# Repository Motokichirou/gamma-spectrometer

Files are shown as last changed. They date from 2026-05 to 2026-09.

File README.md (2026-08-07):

<h1 align="center">Гамма-спектрометр на NaI(Tl)</h1>

<p align="center">
  
  
  
  
  
  
  
</p>

<!-- README-I18N:START -->
<p align="center"><b>Русский</b> | <a href="./README.en.md">English</a></p>
<!-- README-I18N:END -->

Портативный цилиндрический гамма-спектрометр на кристалле NaI(Tl) Ø63×63 мм и ФЭУ Hamamatsu R1307, с интерфейсом USB-C, совместимым с [BecqMoni](https://github.com/Am6er/BecqMoni) / AtomSpectra (протокол shproto).

> 📚 **Документация:** [обзор аппаратной части](docs/ru/hardware.md) · [прошивка](docs/ru/firmware.md) · [протокол shproto](docs/ru/protocol.md) · [ПО на PC](host/README.md) · [симуляции](docs/ru/simulations.md)

---

## Ключевые характеристики

| Параметр | Значение |
|---|---|
| Детектор | NaI(Tl) Ø63×63 мм |
| ФЭУ | Hamamatsu R1307 (8 каскадов, Ø76 мм) |
| Диапазон энергий | 50 кэВ – 3.5 МэВ |
| Целевое FWHM @ Cs-137 | 6.0–6.5 % |
| Каналов спектра | 8192 |
| Скорость счёта | до ~30 000 имп/с |
| МК | STM32G474 @ 170 МГц (12-бит АЦП, 4 Мвыб/с) |
| ВВ питание | 0 … −1500 В (MAX1847 + 8-ступенчатый умножитель CW) |
| Интерфейс | USB-C → UART 600 кбит/с (FT231X), протокол shproto |
| Питание | USB 5 В, ~370 мА |
| Форм-фактор | Цилиндрический стек, платы Ø45 мм |

---

## Аппаратная архитектура

### Стек плат (снизу → вверх)

```
 ┌─────────────────────────────────────────┐
 │  USB/Power board  Ø45 mm               │  ← кабель USB-C
 │  LP5907 · AMS1117 · TPS60400 · FT231X  │
 ├─────────────────────────────────────────┤
 │  HV board         Ø45 mm               │
 │  MAX1847 · IRLML0040 · CW ×8 · −1500 V │
 ├─────────────────────────────────────────┤
 │  MCU board        Ø45 mm               │
 │  STM32G474 · CR-RC² shaper · ADC · SPI │
 ├─────────────────────────────────────────┤
 │  Divider board    Ø42–45 mm            │  ← ФЭУ Hamamatsu R1307 + NaI(Tl)
 │  R1307 divider · MMBTA42 buffers       │
 │  ADA4817-1 TIA (Zt = 499 Ω)            │
 └─────────────────────────────────────────┘
```

Межплатные соединения:
- **Сигнал**: коаксиал RG-178 + U.FL (делитель → МК, ~470 мВ для Cs-137)
- **Питание ±5 В_A**: JST PH 3-пин (МК → делитель)
- **−HV**: экранированный провод ≥5 кВ вдоль края стека (ВВ → делитель)
- **Все прочие сигналы**: pin-header 2×N с шагом 2.54 мм

### Цепь сигнала

```
NaI(Tl) + R1307            Плата делителя                 Плата МК
─────────────    ─────────────────────────────   ──────────────────────────────────
 Сцинтилляция →   Делитель (цепочка 7.72 МОм)   →  CR  (OPAMP1, τ=1 мкс)
 τ_спада=230 нс   Активные буферы (Dy6/7/8)        RC  (OPAMP2, τ=510 нс)
 I_анода(Cs-137)  ADA4817 TIA, Zt=499 Ω, BW≈92 МГц →  PGA ×4 (OPAMP3)
  = 0.94 мА       V_вых = +469 мВ (Cs-137)         V_ADC = baseline 0.408 В
                                                   ADC1_IN12, 4 Мвыб/с
                                                   гистограмма 8192 кан. → USB
```

**Полярность АЦП:** анод забирает ток ⇒ выход TIA вверх ⇒ импульсы **положительны** относительно baseline 0.408 В → `amplitude = sample − baseline`

### Калибровка энергии (по симуляции, модель OPAMP G474)

| Источник | Энергия | Канал АЦП / 8192 |
|---|---|---|
| Am-241 | 59.5 кэВ | 105 |
| Cs-137 | 662 кэВ | 1159 |
| Co-60 | 1.33 МэВ | 2321 |
| Tl-208 | 2.61 МэВ | 4554 |
| Потолок | 3.5 МэВ | 6133 |

---

## Статус проекта

| Задача | Статус |
|---|---|
| Схема — плата USB/питания | ✅ Готово (ERC 0) |
| Схема — плата ВВ | ✅ Готово (ERC 0) |
| Схема — плата МК | ✅ Готово (ERC 0) |
| Схема — плата делителя | ✅ Готово (ERC 0) |
| LTspice: вход TIA (ADA4817) + делитель | ✅ Валидировано (`sim_divider_complete`: Zt=499 Ω, буферы смещены ~96 мкА, диоды B-E) |
| LTspice sim2: шейпер CR-RC² | ✅ Готово (PF=0.202, ширина импульса ~1.5 мкс) |
| LTspice sim3: бюджет шумов | ✅ Готово (σ=76.9 мкВ rms с TIA, 0.25 кан.; 94.4 с прежним AD8000) |
| BOM с MPN + footprint | ✅ Готово (177 комп.: 74 конд. / 17 MPN, 63 R, все активные) |
| Разводка PCB | 🚧 2 слоя, все 4 платы разведены, паритет со схемой 0. Нормы ВВ-зазоров (3 мм/кВ) заданы в `.kicad_dru`. ⚠ Осталось развести 59 мест, где земля подходит к ВВ-цепям ближе нормы |
| Прошивка STM32 | 🚧 Этапы 1–2 + самотест + энергокалибровка во flash работают на Nucleo (shproto, реальная гистограмма); этап 3 — на боевой плате |
| ПО на PC `gammapult` | 🚧 Связь, диагностика, живой спектр, мастер энергокалибровки (GUI + CLI, единый .exe); калибровка совместима с кнопками BecqMoni |

---

## Структура репозитория

```
gamma-spectrometer/
├── docs/
│   ├── adc_mcu_board.md              # Плата МК v1.6 — полная техническая документация
│   ├── divider_board.md              # Плата делителя + ADA4817 TIA
│   ├── usb_power_board.md            # Плата USB/питания — обзор
│   ├── usb_power_board_schematic.md  # Плата USB/питания — детальная схема
│   ├── hv_board_schematic.md         # Плата ВВ — детальная схема
│   ├── cheatsheet_mistakes.md        # Правила проверки и журнал прошлых ошибок
│   └── refs/                         # Даташиты
├── firmware/                         # Прошивка STM32G474 (этапы 1–2 на Nucleo работают)
├── host/                             # ПО на PC `gammapult` (Win32/ImGui, GUI + CLI)
├── pcb/
│   └── gamma_spectrometer/           # Проект KiCad (все 4 платы)
└── simulation/
    ├── models/                       # SPICE-модели (opamp_g474, ADA4817, AD8000)
    ├── scripts/                      # Python-скрипты анализа
    ├── sim1_ad8000.cir               # Устойчивость и полоса AD8000
    ├── sim2_shaper.cir               # Формирователь импульсов CR-RC²
    └── sim3_noise.cir                # Полный бюджет шумов
```

---

## Бюджет шумов (sim3)

| Вклад | FWHM |
|---|---|
| Статистика ФЭУ R1307 + NaI(Tl) | 6.3 % |
| Пульсации ВВ (типично) | 0.3–0.5 % |
| Нелинейность АЦП (12-бит, ENOB ~10.5) | 0.1 % |
| Шум электроники (σ = 94.4 мкВ rms) | **0.064 %** |
| **Итого** | **~6.32 %** |

Шум электроники **на два порядка ниже** статистики ФЭУ — разрешение ограничено ФЭУ, а не электроникой.

---

## Протокол: shproto / AtomSpectra

Совместим с [BecqMoni](https://github.com/Am6er/BecqMoni) и [nanopro](https://github.com/Am6er/nanopro).

- UART 600 000 бит/с, 8N1
- Кадр: `0xFE | CMD | PAYLOAD (с байт-стаффингом) | CRC16-MODBUS | 0xA5`
- Cmd `0x01`: спектр (до 8192 × 32-битных каналов)
- Cmd `0x04`: статус (прошедшее время, CPS, число невалидных импульсов)
- Keep-alive: `0xFF` от ПК каждую ~1 с

---

## Лицензия

Файлы аппаратного дизайна (KiCad, LTspice) — [CERN OHL-S v2](https://ohwr.org/cern_ohl_s_v2.txt)  
ПО (прошивка, host) — [MIT](https://opensource.org/licenses/MIT)

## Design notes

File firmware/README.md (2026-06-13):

# Прошивка STM32G474 — гамма-спектрометр

## Этапы разработки

| Этап | Железо | Цель | Статус |
|---|---|---|---|
| **1** | Nucleo-G474RE | shproto через VCP → BecqMoni рисует тестовый спектр | ✅ работает |
| **2** | Nucleo-G474RE | DAC→ADC петля: синтетические импульсы, peak detect, реальная гистограмма | ✅ работает |
| 3 | Боевая MCU board | OPAMP-шейпер, реальные импульсы, HV, Pt1000-термокомпенсация | ⏳ ждёт железа |

Дополнительно реализованы: подсистема самотеста (`-tst`), настраиваемый порог DSP
(`-thr`) и энергокалибровка во flash (`-cal`/`-rcal`/`-wcal`, совместимая с BecqMoni —
см. [docs/ru/protocol.md](../docs/ru/protocol.md)).

## Структура

```
firmware/
├── core/                 # Переносимые модули (без HAL — компилируются где угодно)
│   ├── shproto.h/.c      # Протокол BecqMoni: CRC16 MODBUS, стаффинг, парсер, билдер
│   ├── spectrum.h/.c     # Гистограмма 8192
│   ├── dsp.h/.c          # Детектор импульсов: baseline, pile-up, LSQ-фит вершины
│   ├── pulsegen.h/.c     # Генератор тест-импульсов (источник самотеста)
│   ├── selftest.h/.c     # FSM самотеста ENC / линейности
│   └── app.h/.c          # Команды (-sta/-sto/-rst/-inf/-cal/-rcal/-wcal/-calclr/-thr/-tst) + спектр/статус 1 Гц
├── gamma_stage1/         # Проект CubeIDE (Nucleo): клей HAL, stage2_hw.c (DAC/ADC/DSP), cal_store.c (flash)
├── nucleo_stage1/
│   └── main_glue.c       # Шаблон интеграции в CubeMX-проект (копировать в USER CODE)
├── tools/                # becqmoni_sim.py, flash_stage1.cmd
└── README.md
```

`core/` не зависит от HAL — связь с железом через функции-порты (`app_port_uart_send`,
`app_port_millis`, `app_port_temperature_c`), которые реализуются в main.c. Слабые хуки
калибровки переопределяются в `cal_store.c`. Этот же код без изменений поедет на боевую
плату.

## Этап 1 — пошаговая инструкция

### 1. Установить STM32CubeIDE
https://www.st.com/en/development-tools/stm32cubeide.html (бесплатно, ~1 ГБ).

### 2. Создать проект
1. File → New → STM32 Project
2. Вкладка **Board Selector** → `NUCLEO-G474RE` → Next
3. "Initialize all peripherals with their default Mode?" → **Yes**
   (CubeMX сам назначит LPUART1 на PA2/PA3 — это VCP через ST-LINK)

### 3. Настроить в CubeMX (.ioc)
1. **Clock Configuration:** HCLK = **170 МГц**
   - источник PLL: HSI16, PLLM=4, PLLN=85, PLLR=2
   - CubeMX сам включит Boost mode (R1MODE) при 170 МГц
2. **LPUART1** (Connectivity): Asynchronous, **600000** бод, 8N1
3. **DMA** (вкладка DMA Settings у LPUART1): Add → `LPUART1_RX`,
   Mode = **Circular**, Data Width = Byte
4. Сгенерировать код (Ctrl+S → Generate)

### 4. Подключить core/
1. Скопировать `firmware/core/*.c` в `Core/Src/`, `firmware/core/*.h` в `Core/Inc/`
   (или: Project Properties → C/C++ General → Paths → добавить путь к `firmware/core`)
2. Перенести куски из `nucleo_stage1/main_glue.c` в `Core/Src/main.c`
   в соответствующие секции `USER CODE` (номера секций — в комментариях шаблона)

### 5. Собрать и прошить
Build (молоток) → Run (зелёная стрелка). Прошивается через встроенный ST-LINK.

### 6. Проверить с BecqMoni
1. Узнать номер COM-порта ST-LINK VCP (Диспетчер устройств → Ports)
2. BecqMoni: настройки устройства → AtomSpectra (shproto), COM-порт, **600000 бод**
3. **Каналов: 8192** (иначе BecqMoni будет даунсемплить)
4. Подключиться → старт набора
5. Ожидаемо: накапливающийся спектр с пиками на каналах **101** (как Am-241 59.5 кэВ)
   и **1138** (как Cs-137 662 кэВ), ~500 cps

### Если не работает
- Терминалом (PuTTY, 600000 8N1) на COM-порт: должен идти бинарный поток после `-sta`
- Проверить что LPUART1, а не USART2 подключён к VCP (UM2505, солдер-бриджи SB)
- BecqMoni шлёт при подключении `-sto`→`-rst`→`-sta` и ждёт `-ok` на каждую

## Протокол shproto (краткая шпаргалка)

```
Кадр: 0xFF 0xFE [CMD][PAYLOAD...][CRC_LSB][CRC_MSB] 0xA5
Стаффинг: 0xFE/0xFD/0xA5 внутри кадра → 0xFD + ~байт
CRC16 MODBUS (init 0xFFFF, poly 0xA001) по нестаффленным CMD+PAYLOAD
CMD: 0x01 спектр [offset u16][ch u32 ×N]; 0x03 текст; 0x04 статус (триггер отрисовки!)
Статус: [elapsed_СЕК u32][cpu_load u16][cps u32][invalid u32]  (elapsed в СЕКУНДАХ!)
```

Полная спецификация: `docs/session_context.md` → «Протокол shproto».

## Этап 2 — выполнено ✅

Петля DAC→ADC замкнута целиком на кристалле Nucleo (перемычка PA4/A2 → PA0/A0):
TIM7 (пуассон) → DAC1+DMA (форма CR-RC²) → ADC1 circular DMA @2.83 Мвыб/с → DSP
(`dsp.c`: baseline, pile-up, LSQ-фит вершины) → гистограмма. Подробности и архитектура
термокомпенсации — в [docs/ru/firmware.md](../docs/ru/firmware.md) и
`docs/adc_mcu_board.md` (раздел 8).

## Дальше (этап 3)

- Перенос на боевую MCU board: внутренние OPAMP-шейпер CR-RC², реальные импульсы ФЭУ.
- Термокомпенсация по Pt1000 (g(T)), управление ВВ.
- Сервисное ПО `gammapult` (см. [host/README.md](../host/README.md)).

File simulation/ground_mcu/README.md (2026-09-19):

# ground_mcu — резистивная модель земли платы МК (2026-09-19)

Вопрос: насколько токи по земле платы МК сдвигают опорные точки аналогового тракта и что это даёт
на входе АЦП и на ВВ (через HV_CONTROL). Модель верна для постоянного тока и НЧ (≲1 МГц);
индуктивность на фронтах и ёмкостные наводки сюда не входят.

## Запуск

```
"C:\Program Files\KiCad\9.0\bin\python.exe" simulation/ground_mcu/extract_geom.py   # геометрия из .kicad_pcb (только чтение)
python simulation/ground_mcu/spice_transfer.py                                     # передача смещений земли на АЦП (LTspice)
python simulation/ground_mcu/solve_ground.py                                       # сетка резисторов + итоговые таблицы
```

⚠ Читается сохранённый файл платы и **сохранённая заливка** — перед расчётом в Pcbnew залить зоны (`B`) и сохранить.

## Модель

- Медь GND обоих слоёв на сетке 0.1 мм, 35 мкм → 0.49 мОм/кв; GND-виа 1.5 мОм между слоями.
- Выходы в стек: 3 GND-цанги + 3 стойки, по 3 мОм до «земли стека» (оценка).
- Токи (оценки): VDD МК 30 мА DC / вариации 10 мА (DS12288, Run 170 МГц); VDDA ≈ 4.5 мА
  (3 ОУ × 1.3 + АЦП 0.59 мА при 4 Мвыб/с) / вариации 1 мА; флеш 15 мА (только запись калибровки);
  ток делителя через оплётку 0.7 мА (пик Dy8 на 3.5 МэВ); ШИМ HV_CONTROL через C312 0.165 мА.
- Шаблоны токов: `A_*` — возврат в стек, `L_*` — местная петля «развязка → вывод питания МК».

## Как смещение земли проходит на АЦП (spice_transfer.py, топология V2 из fix_c320)

| точка земли | 10 кГц | 160 кГц | 2 МГц |
|---|---|---|---|
| **gA** — низ делителя A (R313, C321) | ×2.0 | ×1.8 | ×3.5 |
| **gT** — оплётка коаксиала (COAX3) | ×2.0 | ×2.2 | ×0.5 |
| gB — низ делителя B (R311) | ×0.07 | ×0.004 | ≈0 |
| gR — земля опоры U301 | ×0.04 | ×0.002 | ≈0 |

Правило разводки: GND R313/C321 и пятак оплётки — рядом с VSSA (вывод 27), без чужих токов между ними.

## Результат по плате от 2026-09-19 17:19

Связность: все GND-выводы U302 подключены (вывод 15 — дорожкой и виа, 17:19); 40, 50, 61, 79 держатся
на одной спице (`starved_thermal`). R(VSSA → земля стека) = 4.3 мОм.

| источник тока | ток | на входе АЦП @160 кГц | в каналах | на ВВ через HV_CONTROL | при сплошном B.Cu под аналогом |
|---|---|---|---|---|---|
| цифра МК → стек | 10 мА | 22.3 мкВ | 0.07 | 2.2 мВ | 2.8 мкВ |
| VDDA → стек | 1 мА | 14.3 мкВ | 0.05 | 0.2 мВ | 9.9 мкВ |
| флеш (запись) | 15 мА | 17.5 мкВ | 0.06 | 3.6 мВ | 1.8 мкВ |
| делитель через оплётку | 0.7 мА | 0.18 мкВ | 0.0006 | 0.2 мВ | 0.5 мкВ |
| ШИМ HV_CONTROL | 0.165 мА | 0.26 мкВ | 0.0009 | 0.01 мВ | 0.004 мкВ |
| ВЧ-петля развязки МК | 10 мА | 16.3 мкВ | 0.05 | 0.03 мВ | 2.0 мкВ |
| ВЧ-петля VDDA | 1 мА | 14.7 мкВ | 0.05 | — | 9.7 мкВ |

Ориентиры: 1 канал = 305 мкВ, шум тракта 78 мкВ rms, пик Cs-137 на АЦП 354 мВ; ВВ ~1000 В.

Вывод 15 стоит на «аналоговой» стороне корпуса (рядом PA1–PA3), поэтому после его подключения часть
цифрового тока идёт ближе к опорным точкам шейпера: цифра выросла с 12 до 22 мкВ — по-прежнему мало.

**Вывод:** резистивные падения по земле МК — не более ~25 мкВ на входе АЦП (< 0.1 канала, в 3 раза
ниже шума) и единицы мВ на ВВ (единицы ppm). На спектр не влияют. Сплошной B.Cu под аналоговой
зоной уменьшает их в 2–10 раз, но они и так малы. Оставшиеся риски — ВЧ (индуктивность петель,
ёмкостные наводки на узлы шейпера над разрывами земли), в эту модель не входят.

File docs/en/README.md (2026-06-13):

# Documentation

<!-- README-I18N:START -->
[Русский](../ru/README.md) | **English**
<!-- README-I18N:END -->

English documentation set for the NaI(Tl) gamma spectrometer.
For the project overview, see the root [README](../../README.en.md).

| Document | Contents |
|---|---|
| [hardware.md](hardware.md) | Board stack, signal chain, and a summary of all four boards |
| [firmware.md](firmware.md) | STM32G474 firmware: portable core, development stages, pulse DSP, self-test |
| [protocol.md](protocol.md) | shproto / AtomSpectra serial protocol reference |
| [simulations.md](simulations.md) | LTspice simulations (AD8000, CR-RC² shaper, noise) and the noise budget |

> The detailed engineering notes for each board (`docs/adc_mcu_board.md`,
> `docs/divider_board.md`, `docs/hv_board_schematic.md`,
> `docs/usb_power_board_schematic.md`) are maintained in Russian. The documents
> here are a curated English summary for an international audience.

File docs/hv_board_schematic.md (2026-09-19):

# Плата ВВ питания — схемотехника

## Назначение
Средняя плата стека. Генерирует регулируемое высокое напряжение 0 … −1500 В
для ФЭУ R1307. Управляется сигналом HV_CONTROL от платы МК.
Питается напрямую от +5В USB через шину +5V_HV нижнего header'а.

## Стек и межплатные соединения

```
┌─ Плата МК (сверху) ──────────────────────────────────────────┐
│  Верхний 2×N header (размер при разводке)                      │
│  HV_CONTROL → (с платы МК вниз к нам)                         │
│  HV_MONITOR ← (от нас вверх к плате МК)                       │
└────────────────────────────────────────────────────────────────┘
            ↕ верхний header 2×N
┌─ Плата ВВ (эта плата) ───────────────────────────────────────┐
│  MAX1847 → IRLML0060 → ATB322524 → ×8 CW → −HV               │
│                              │                                 │
│                        шиль. кабель → плата делителя           │
└────────────────────────────────────────────────────────────────┘
            ↕ нижний header 2×N
┌─ USB/питание (снизу) ────────────────────────────────────────┐
│  +5V_HV — силовой, ≤ 200 мА                                    │
│  +5V_A, +3.3V_A, +3.3V_D, −5V_A, GND, UART, LED, SWD, ...   │
└────────────────────────────────────────────────────────────────┘
```

---

## 1. Питание +5V_HV

Приходит с USB/Power board через шину **+5V_HV** нижнего header'а.  
Bulk-фильтр (L103 100мкГн + C115 47мкФ) **находится на USB/Power board** — перед header'ом, чтобы помехи MAX1847 @ 252 кГц не попадали в +5V_USB шину.

Локальный bypass на HV board:
```
+5V_HV ─┬─ C204 100нФ X7R ── GND   (у MAX1847 IN pin 15)
         ├─ C206 47мкФ X5R  ── GND   (bulk, у T201 pin 1)
         └─ C207 100нФ X7R ── GND   (ВЧ развязка, у T201 pin 1)
```
C206+C207 стоят прямо перед pin 1 T201 — компенсируют паразитную индуктивность header'а при пиковых токах переключения.

Локальный LDO (+3.3V_local) **отсутствует** — убран за ненадобностью. TL431 (Vref_2.5В) питается напрямую от +5V_HV.

---

## 2. MAX1847EEE+ — контроллер ВВ

**Корпус:** QSOP-16

| Пин | Функция | Подключение |
|---|---|---|
| IN (15) | Вход питания | +5V_HV |
| VL (2) | Внутренний LDO ~4.25В | Развязка C202 0.47мкФ к GND; POL соединён с VL |
| PGND (12) | Силовая земля | GND |
| GND (10,11) | Сигнальная земля | GND |
| GATE / EXT (14) | Затвор MOSFET | → R206 10Ом → Q201 IRLML0060 Gate |
| CS (13) | Датчик тока | узел Source Q201; R205 (0.1Ом) к GND; параллельно C205 100пФ X7R |
| FREQ (3) | Задание частоты | R202 180кОм к GND |
| COMP (4) | Компенсация петли | R201 1МОм → C201 33нФ → GND (последовательно) |
| REF (5) | Опорное 1.25В | Развязка C203 0.1мкФ к GND (вых., не нагружать) |
| FB (6) | Обратная связь | ← R207/R209–R217 (10×100МОм от CW_out) + R208 (2.2МОм от HV_CONTROL) |
| SHDN (8) | Отключение (LOW=выкл) | ← R204 10кОм (от MCU HV_ENABLE); R203 100кОм к GND |
| POL (1) | Полярность N-ch | → VL (pin 2) |
| SYNC (16) | Синхронизация | GND (не используется) |

**Частота переключения:**

Задаётся только резистором R202 по формуле даташита:
```
T = 5.21×10⁻⁷ + 1.92×10⁻¹¹ × R202 − 4.86×10⁻¹⁹ × R202²   (R202 в Омах)
f_sw = 1 / T
```
При R202 = 180 кОм (180000 Ом):  T ≈ 3.96 мкс → **f_sw ≈ 252 кГц**

**HV_ENABLE (прямое подключение от MCU, активный HIGH):**
```
MCU HV_ENABLE (PB10) ── R204 10кОм ── SHDN (pin 8)
                                            │
                                        R203 100кОм
                                            │
                                           GND
```
- MCU HV_ENABLE = **HIGH (3.3В)** → SHDN = HIGH → MAX1847 работает → HV включён
- MCU HV_ENABLE = LOW / floating → SHDN подтянут к GND через R203 → MAX1847 остановлен → **HV = 0В**

Безопасное состояние по умолчанию: при сбросе или отсутствии команды MCU — HV выключено.
R204 (10кОм) защищает GPIO MCU от помех с HV-платы. При V_SHDN = 3.3В > V_IH ≈ 3В (0.7×VL) — порог надёжно пройден.

---

## 3. Первичный контур: IRLML0060 + ATB322524

### IRLML0060 — силовой ключ
- N-MOSFET, SOT-23 (1 — G, 2 — S, 3 — D, как прежний IRLML0040), **Vds = 60 В**, Id = 2.7 А,
  RDS(on) 92 мОм макс @10 В / 116 мОм макс @4.5 В, VGS(th) 1.0–2.5 В, Qg 2.5 нК, C_oss 37 пФ, tf 4.2 нс
  (`docs/refs/IRLML0060.pdf`, Infineon). Заменил IRLML0040 (40 В) 2026-09-19 — см. бюджет выброса ниже.
- Затвор ← MAX1847 GATE
- Исток → R205 (0.1Ом) → PGND (датчик тока для CS MAX1847)
- Сток → T201 pin 4 (конец первичной обмотки)

**Паразитные эффекты IRLML0060 при 252 кГц:**

| Эффект | Параметр | Последствие | Решение |
|---|---|---|---|
| Выброс на Drain при выключении | L_lk=0.4мкГн + C_oss=37пФ | пик 38.8 В типично, 43–45 В в худшем случае | Снаббер BAS516+C208+2×BZT52C18 + ключ на **60 В** (IRLML0060): запас ≥15 В |
| Эффект Миллера (C_gd ≈ 16пФ) | При нарастании V_drain ток через C_gd подзаряжает затвор обратно | Замедляет выключение, увеличивает потери переключения | R206=10Ом ограничивает скорость и контролирует dV/dt |
| Потери в C_oss | ½×37пФ×36²×252кГц ≈ 6мВт | Нагрев транзистора | Пренебрежимо мал |
| Осцилляция затвора | Паразитная индуктивность трасс PCB + C_gd → ВЧ-звон на Gate | Ложные включения, нестабильность | R206=10Ом давит осцилляцию; минимальная длина трассы Gate |

**Снаббер — детальная работа:**

При выключении Q201 ток первичной обмотки (через L_lk) не может оборваться мгновенно. V_drain начинает расти:
1. BAS516 открывается (Анод = Drain, потенциал растёт выше уровня катода)
2. Ток втекает в C208 (10нФ) — демпфирует звон, ограничивает скорость нарастания dV/dt
3. Когда V_drain достигает ~36В — открываются D202+D203 (2×BZT52C18 последовательно = 36В)
4. Избыточная энергия рассеивается в зенерах — V_drain зафиксировано на ~36В

**Бюджет выброса на стоке (расчёт 2026-09-19).** «36 В» — только номинал двух стабилитронов при 25 °C; к пику
прибавляется прямое падение BAS516 (напряжения диода и стабилитронов складываются — так и задумано референсом):

| слагаемое | типично | худший случай |
|---|---|---|
| пробой 2×BZT52C18 (16.8–19.1 В каждый, ТКН ≈ +0.09 %/°C) | 36.0 В | 38.2 В; +1.5 В при 70 °C |
| + VF BAS516 на пиковом токе 0.8–1.0 А | 1.4 В | 2.0 В |
| + подзаряд C208 за импульс (L_lk·I²/2 в 10 нФ) | 0.6 В | 0.9 В |
| + L·dI/dt петли «сток → D201 → C208 → земля → исток» (6–10 нГн, фронт 4–6 нс) | 0.8 В | 2.5 В |
| **пик на стоке** | **38.8 В** | **43.6 В (25 °C) / 45.1 В (70 °C)** |

С прежним IRLML0040 (40 В, лавина НЕ нормирована) запас был ~+1 В типично и отрицательный в худшем случае.
**Решение: Q201 = IRLML0060 (60 В), та же посадка SOT-23** — запас ≥15 В, снаббер без изменений.
Снаббер всё равно держать **максимально близко к Drain Q201 и T201 pin4** (слагаемое L·dI/dt).
На стенде: осциллограф на стоке при полном ВВ под нагрузкой делителя, щуп с короткой пружиной на землю.

### ATB322524-0110-T000 (TDK) — трансформатор
| Параметр | Значение |
|---|---|
| Производитель | TDK |
| Корпус | SMD 3.2×2.5×2.4 мм (1210/JIS) |
| Коэффициент трансформации | 1 : 10.2 |
| Индуктивность первичной | 7.0 ± 20% мкГн @ 100кГц |
| DCR первичной | 0.5 Ом макс |
| DCR вторичной | 60 Ом макс |
| Индуктивность рассеяния | 0.4 мкГн макс |
| Напряжение изоляции | 500 В rms |
| Номинальный ток | 0.7 А rms |

**Подключение:**
```
+5V_HV ─── T201 pin 1 (начало первичной обмотки, dot)
            T201 pin 4 (конец первичной) ─── IRLML0060 Drain ─── Анод D201 (BAS516)
            T201 pin 2 (начало вторичной, dot) ─── GND
            T201 pin 3 (конец вторичной) ─── C209 1нФ (первый конденсатор CW умножителя)
```

**Полярность вторичной обмотки:**
- Q201 включён: pin3 уходит в плюс (+94В), pin2 = GND → конденсаторы CW заряжаются
- Q201 выключён (флайбэк): pin3 уходит в минус → BAV23S умножителя проводят → −HV нарастает

### Снаббер первичного контура (RC + zener, по схеме референса)
```
T201 pin4 / Q201 Drain ─── D201 (BAS516) Анод
                            D201 Катод ─┬─ C208 10нФ ─── GND
                                        ├─ D202 (BZT52C18) Катод
                                             D202 Анод ─── D203 (BZT52C18) Катод
                                                           D203 Анод ─── GND
```
- **D201 BAS516** (SOD-523): быстрый диод, пропускает бросок Drain в снаббер
- **C208 10нФ**: демпфирует высокочастотный звон
- **D202 + D203** (два BZT52C18, SOD-123, последовательно): суммарный зенер 36В → ограничивают V_drain до ~36В
- Пик на стоке 38.8 В типично / до ~45 В в худшем случае (см. бюджет выше) → ключ IRLML0060 на **60 В**

**Датчик тока Q201:**
```
Q201 Source ─┬─ CS (pin 13 MAX1847)
             ├─ R205 0.1Ом ─── GND
             └─ C205 100пФ ─── GND   (фильтр помех CS, параллельно R205)
```

**Рабочий цикл:**
- Vторичн_пик = Vвх × (Ns/Np) × D/(1-D) = 5В × 10.2 × 0.65/0.35 ≈ **94.6В** при D=0.65
- MAX1847 регулирует D в диапазоне, поддерживая заданное выходное напряжение

### Паразитные эффекты трансформатора при 252 кГц

**1. Индуктивность рассеяния (L_lk = 0.4 мкГн макс)**
Часть энергии, накопленной в первичке, не передаётся во вторичную обмотку — она сосредоточена в поле рассеяния. При выключении Q201 ток через L_lk не может оборваться мгновенно — возникает выброс напряжения на Drain. Именно L_lk является главной причиной применения снаббера (BAS516 + C208 + 2×BZT52C18). Рекомендация по PCB: минимальная площадь петли T201–Q201–C206/C204 для уменьшения паразитной индуктивности трасс, усиливающей выброс.

**2. Межобмоточная ёмкость (C_winding)**
Первичная и вторичная обмотки ёмкостно связаны. Быстрые перепады dV/dt на Drain при переключении (252 кГц) просачиваются через эту ёмкость прямо в высоковольтный выход CW умножителя, инжектируя высокочастотный шум. Это дополнительное обоснование необходимости 3-каскадного RC-фильтра после CW (раздел 5): он подавляет не только пульсации умножителя, но и этот кондуктивный шум.

**3. Потери в сердечнике**
При 252 кГц в феррите присутствуют два вида потерь:
- Гистерезисные (∝ f): перемагничивание сердечника за каждый цикл
- Вихревые токи (∝ f²): индуцированные токи в сердечнике

ATB322524 — ферритовый трансформатор, оптимизированный для диапазона 100 кГц–1 МГц. Частота 252 кГц находится в его нормальной рабочей точке.

**4. Скин-эффект в обмотках**
При 252 кГц глубина проникновения тока в медь:
```
δ = 66 / √252000 ≈ 0.13 мм
```
Ток вытесняется к поверхности проводника → эффективное AC-сопротивление обмоток превышает DCR (0.5 Ом первичка / 60 Ом вторичка). Вызывает небольшой дополнительный нагрев трансформатора, при токе 115 мА пренебрежимо мал.

**Итог:** все паразитные эффекты учтены в схемотехнике — снаббер (L_lk), RC-фильтр (C_winding), выбор компонента (потери в сердечнике), тепловой режим (скин-эффект).

### BAV23S в CW умножителе при 252 кГц

BAV23S используется как один диод (2 последовательных диода = 500В обратного напряжения, pin3 = NC).

- **Обратное напряжение на пару:** 2 × V_пик ≈ 375В < 500В ✓
- **Время обратного восстановления:** t_rr ≈ 50нс; доля периода: 50нс / 3970нс ≈ 1.3% — ток обратного восстановления пренебрежимо мал
- **Ток через конденсатор 1нФ:** I ≈ C × ΔV/Δt ≈ 90 мкА — потери на восстановление незначительны
- **Вывод:** диоды справляются с частотой 252 кГц без ограничений ✓

---

## 4. Вторичный контур: CW умножитель × 8

Вторичная обмотка T201 (pin3) подключается **напрямую** к первому конденсатору C209 CW умножителя — отдельный выпрямительный диод на вторичной стороне **отсутствует**. Функцию выпрямления выполняют диоды BAV23S внутри умножителя.

### Умножитель Кокрофта-Уолтона, 8 ступеней

**Конденсаторы:** 8 × **1нФ X7R 500В 0805** ±10%
Каждый конденсатор в ступени: V_ступени ≈ 94.6В, рабочее < 500В ✓

**Диоды:** 8 × **BAV23S** (SOT-23-3, два диода в корпусе, 250В, 200мА)
Итого 16 диодов = 8 полных ступеней умножителя.

**Расчёт (идеальный):**
```
V_out = 2 × n × V_пик = 2 × 8 × 94.6В ≈ 1514В → MAX1847 регулирует до ≤ 1500В ✓
```

Каждый диод BAV23S видит обратное напряжение 2 × 94.6В = 189В < 250В ✓

**Выходные накопительные конденсаторы:**
```
CW_out ─── C13a201─C13b201 (2× 0.1мкФ/1кВ в серии = 50нФ/2кВ) ─── GND
       └── C14a201─C14b201 (2× 0.1мкФ/1кВ в серии = 50нФ/2кВ) ─── GND
```
Тип: **C1812X104K102T (Holy Stone)** — 0.1мкФ X7R 1кВ, корпус 1812. По 2 штуки последовательно на каждую позицию (C13a201+C13b201 = одна позиция C13a201/C13b201).
⚠ Рабочее напряжение узла = полное выходное ВВ (~1500В). Только ВВ-исполнение ≥2кВ. Типовые 25В/100В керамика **недопустимы**.

---

## 5. RC-фильтры выхода

Три каскада RC-фильтрации для подавления пульсаций умножителя:

```
CW_out ─── R220 100кОм ─── node1 ─── R231 100кОм ─── node2 ─── R232 100кОм ───┬─── −HV_out
                    │                         │                           │      │
  C15a201─C15b201 2×0.1мкФ/1кВ  C16a201─C16b201 2×0.1мкФ/1кВ  C17a201─C17b201 2×0.1мкФ/1кВ  R233 10Ом
                    │                         │                           │      │
                   GND                       GND                         GND  C18a201─C18b201 2×220пФ C0G/1кВ = 110пФ/2кВ
                                                                               │
                                                                              GND
```
ВЧ фильтр R233+C18a201/C18b201 стоит **на выходе** (−HV_out), прямо перед нагрузкой (ФЭУ).
Напряжение на C18a201/C18b201 ≈ 1442В → 2× CC1206JKNPOCBN221 (220пФ C0G 1кВ 1206) последовательно = **110пФ / 2кВ**.
C0G обязателен: X7R при высоком DC-смещении теряет ёмкость, C0G стабилен.

Каждая позиция C15a/b201, C16a/b201, C17a/b201: **2× C1812X104K102T (Holy Stone) последовательно** (0.1мкФ / 1кВ X7R 1812):
- C_eff = 50нФ (0.1мкФ / 2), V_rating = 2кВ (1кВ × 2)
- Каждый конденсатор видит max 750В << 1кВ ✓
- DC-баланс без резисторов: для одинаковых керамических конденсаторов одной партии допустимо

**Постоянная времени:** RC = 100кОм × 50нФ = **5 мс** на каскад

**Падение напряжения на фильтре** (нагрузка ФЭУ 194 мкА):
194 мкА × 3 × 100кОм = **58В** суммарно при полной нагрузке.
MAX1847 компенсирует это в петле регулирования (closed-loop).

---

## 6. Управление: HV_CONTROL и обратная связь

MAX1847 содержит встроенный усилитель ошибки: регулирует скважность ШИМ так, чтобы **V_FB = 0В**. Внешний усилитель ошибки не нужен.

### Топология делителя FB

```
CW_out ── R207 ── R209 ── R210 ── R211 ── R212 ── R213 ── R214 ── R215 ── R216 ── R217 ── FB (pin 6)
          100М    100М    100М    100М    100М    100М    100М    100М    100М    100М       │
                              суммарно 1 ГОм                                           R208 2.2МОм
                                                                                    │
                                                                             [HV_CONTROL]
```

### Расчёт

Условие регулирования V_FB = 0В. На узле FB сходятся два тока:

```
V_CW / 1ГОм + V_CTRL / 2.2МОм = 0
V_HV = −V_CTRL × (1ГОм / 2.2МОм) = −V_CTRL × 454.5
```

| V_CTRL | V_HV |
|---|---|
| 0В | 0В |
| 3.3В | −1500В |

**HV_CONTROL:** PA8 (TIM1_CH1) PWM → RC-фильтр fc=160Гц → постоянное V_CTRL = 0…3.3В.

### Компоненты

| Ref | Номинал | Корпус | Назначение |
|---|---|---|---|
| R207, R209–R217 | 100МОм (×10) | 1206 | Верхнее плечо FB (суммарно 1ГОм) |
| R208 | 2.2МОм | 0402 | Нижнее плечо: задаёт коэффициент −454.5 |

Напряжение на каждом резисторе цепочки: 1500В / 10 = **150В << 200В** (макс. 1206) ✓

---

## 7. Мониторинг ВВ (HV_MONITOR)

Делитель: Vout− (0…−1500В) → 0…2.5В для MCU ADC (VREF = 2.5В).

```
−HV_out ─── R221–R230 (10 × 6.8МОм 1206 серия) ─── mon_node ─── R219 110кОм ─── катод TL431 (U202, 2.495В)
                                                        │
                                                HV_MONITOR ──── MCU ADC (PA0)
```

Буфер не нужен: R_th на mon_node = 68МОм ∥ 110кОм ≈ **110кОм**. MCU ADC справляется напрямую при времени выборки ≥ 247.5 цикла (требование: ~5.8мкс при ADC clock 42.5МГц).

**Расчёт делителя:**
- R221–R230 суммарно = 68 МОм, R219 = 110 кОм
- V_mon = Vref + (V_HV − Vref) × R219 / (R_chain + R219), где R_chain=68МОм, R219=110кОм
- V_HV = 0В:    V_mon = 2.5 + (0 − 2.5) × 110к/68.11М ≈ **2.496В** ✓ (≈2.5В)
- V_HV = −1500В: V_mon = 2.5 + (−1502.5) × 110к/68.11М ≈ **0.08В** ✓ (≈0В)
- Ток через делитель при 1500В: I = (1500В + 2.5В) / (68МОм + 110кОм) ≈ **22 мкА** (потребление HV цепью минимально)
- Каждый резистор 1206 (6.8МОм): 150В << 200В рабочих ✓

**Источник опорного 2.5В (Vref_2.5В) — TL431DBZ (U202):**
```
+5V_HV ─── R218 1.2кОм ─── Cathode (K)
                                  │
                            REF ──┤ (замкнут на K → V_K = 2.495В)
                                  │
                            C217 100нФ (на REF → GND)
                                 │
                                GND
TL431 Anode (A) ─── GND
```
- R218 задаёт ток катода: I_K = (5В − 2.5В) / 1.2кОм ≈ **2.1 мА** > 0.5 мА min ✓
- C217 (100нФ): стабилизирует TL431 против ВЧ-помех

**Прошивка:** канал PA0 (ADC2_IN1) — установить SampleTime = **247.5 cycles**.

---

## 8. Выход −ВВ на кабель

- Два пятачка с зазором ≥ 3 мм: Vout− и GNDA
- Припаять экранированный провод (изоляция ≥ 5 кВ, напр. ПВВ-1)
- Центральная жила → −HV → катод R1307 (через делитель)
- Оплётка → GNDA → земля делителя

---

## 9. Бюджет потребления

| Источник | Ток | От чего |
|---|---|---|
| MAX1847 + IRLML0060 (нагрузка ФЭУ 194 мкА × 1500В, η ≈ 55%) | ~110 мА | +5V_HV |
| TL431 (U202) 2.495В опора | ~2 мА | +5V_HV |
| **Итого с pin 24** | **~112 мА** | |

Питание MAX1847 и первичного контура — только с шины +5V_HV.
Не нагружает +5V_A и +3.3V_A шины.

**Итого USB 2.0 (при работе):**
- +5V_HV: 112 мА
- Остальные нагрузки USB board (MCU, AD8000, FT231): 258 мА
- **Итого: ~370 мА < 500 мА USB 2.0 ✓**

---

## 10. BOM

| Ref (KiCad) | Компонент | Номинал / MPN | Корпус | Кол. | ~Цена |
|---|---|---|---|---|---|
| U201 | MAX1847EEE контроллер ВВ | MAX1847EEE+ | QSOP-16 | 1 | $3.50 |
| Q201 | IRLML0060 N-MOSFET ключ, 60 В | IRLML0060TRPBF (LCSC C67274) | SOT-23 | 1 | $0.30 | 2026-09-19 заменил IRLML0040 (40 В — мало для выброса стока). ⚠ символ KiCad — от IRLML0030, распиновка та же 1-G/2-S/3-D |
| T201 | Трансформатор 1:10.2 | ATB322524-0110-T000 (TDK) | SMD 3.2×2.5 | 1 | $1.50 |
| D201 | BAS516 снаббер (первичный) | BAS516,215 (Nexperia) | SOD-523 | 1 | $0.10 |
| D202, D203 | BZT52C18 зенер снаббер ×2 | BZT52C18-7-F (Diodes Inc.) | SOD-123 | 2 | $0.20 |
| D204–D211 | BAV23S CW умножитель ×8 | BAV23S,215 (Nexperia) | SOT-23 | 8 | $0.60 |
| U202 | TL431 регулируемый шунт/Vref 2.5В | TL431DBZ (UMW) | SOT-23 | 1 | $0.10 |
| C204 | 100 нФ X7R local bypass (MAX1847 IN pin15) | — | 0402 | 1 | $0.05 |
| C206 | 47 мкФ X7R bulk (у T201 pin1) | GRM32ER71A476KE15L (Murata) | 1210 | 1 | $0.25 |
| C207 | 100 нФ X7R ВЧ развязка (у T201 pin1, парал. C206) | — | 0402 | 1 | $0.05 |
| C202 | 0.47 мкФ VL bypass | — | 0402 | 1 | $0.05 |
| C203 | 0.1 мкФ REF bypass | — | 0402 | 1 | $0.05 |
| C201 | 33 нФ COMP | — | 0402 | 1 | $0.05 |
| C208 | 10 нФ снаббер | — | 0402 | 1 | $0.05 |
| C205 | 100 пФ X7R CS фильтр | — | 0402 | 1 | $0.05 |
| C209–C216 | 1 нФ 500В C0G CW ×8 | CC0805JKNPOBBN102 (YAG) | 0805 | 8 | $0.40 |
| C13a201+C13b201, C14a201+C14b201 | 0.1мкФ X7R 1кВ накопители CW; 2 пары по 2 шт в серии | C1812X104K102T (Holy Stone) | 1812 | 4 | $0.60 |
| C15a/b201, C16a/b201, C17a/b201 | 0.1мкФ X7R 1кВ RC-фильтры; 3 пары по 2 шт в серии | C1812X104K102T (Holy Stone) | 1812 | 6 | $0.90 |
| C18a201+C18b201 | 220пФ C0G/NP0 1кВ ВЧ фильтр; 2 шт в серии = 110пФ/2кВ | CC1206JKNPOCBN221 (YAG) | 1206 | 2 | $0.40 | footprint C_1206_3216Metric ✓ |
| R201 | 1 МОм COMP | — | 0402 | 1 | $0.05 |
| R202 | 180 кОм FREQ | — | 0402 | 1 | $0.05 |
| R205 | 0.1 Ом CS датчик тока | — | 0402 | 1 | $0.10 |
| R206 | 10 Ом затвор Q201 | — | 0402 | 1 | $0.05 |
| R203 | 100 кОм pull-down SHDN → GND | — | 0402 | 1 | $0.05 |
| R208 | 2.2 МОм FB нижнее плечо (HV_CONTROL → FB) | — | 0402 | 1 | $0.05 |
| R204 | 10 кОм защита GPIO MCU → SHDN | — | 0402 | 1 | $0.05 |
| R218 | 1.2 кОм ток через TL431 (U202) от +5V_HV | — | 0402 | 1 | $0.05 |
| C217 | 100 нФ X7R фильтр Vref_2.5В (TL431 Cathode→GND) | — | 0402 | 1 | $0.05 |
| R207, R209–R217 | 100 МОм FB верхнее плечо ×10 (суммарно 1ГОм) | — | 1206 | 10 | $1.00 |
| R220, R231, R232 | 100 кОм RC-фильтры ×3 | — | 0402 | 3 | $0.10 |
| R233 | 10 Ом ВЧ фильтр | — | 0402 | 1 | $0.05 |
| R221–R230 | 6.8 МОм HV_MONITOR ×10 | — | 1206 | 10 | $0.50 |
| R219 | 110 кОм монитор нижнее плечо | — | 0402 | 1 | $0.05 |
| **Итого** | | | | | **~$12.00** |

---

## 11. Требования к PCB

- Зазор −HV/GNDA от любых трасс: ≥ 3 мм (правило 1 мм/500В)
- Резисторы R221–R230 (6.8 МОм 1206): расположить в цепочку, зазор ≥ 1 мм между корпусами
- R207 (100 МОм): максимально далеко от влажных зон, покрыть лаком
- Первичный контур (T201, Q201): компактная петля переключения, минимальная площадь; C204(100нФ) рядом с MAX1847 IN
- CW умножитель: линейная цепочка от T201 pin3 к выходу, нарастающие зазоры к высоковольтному концу
- GNDA ↔ GND: соединять в одной точке (звёздная земля)
- TL431 (U202): близко к mon_node, C217 100нФ — максимально короткие трассы
- **Заливка силиконом** (вся плата после сборки и проверки):
  - Обеспечивает изоляцию ВВ узлов (−1500В) и влагозащиту
  - Заменяет лаковое покрытие — лак не нужен
  - Максимальная высота компонентов ограничена глубиной формы заливки
  - Перед заливкой: убедиться в отсутствии ERC/функциональных ошибок — демонтаж из силикона невозможен
  - Рекомендуемый силикон: ПТК Силагерм или аналог (диэлектрическая прочность ≥ 20 кВ/мм)

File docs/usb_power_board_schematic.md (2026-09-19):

# USB/Power board — схемотехника

> **Статус:** Схема в KiCad (usb_power_board.kicad_sch), ERC ✓

---

## 0. Референсы компонентов (KiCad)

| Ref | Компонент | KiCad символ | Примечание |
|---|---|---|---|
| J101 | USB-C разъём | JAE DX07S024WJ3R400 | 24 пина + 4 shield |
| F101 | PTC 500мА | Device:Polyfuse | MF-MSMF050-2 |
| U_ESD101 | ESD защита | Power_Protection:PRTR5V0U2X | SOT-143 ✓ (подтверждён по даташиту) |
| U103 | FT231XQ | Interface_USB:**FT231XQ** | QFN-20-1EP_4x4mm ✓ (назначен) |
| U101 | LP5907MFX-3.3 | Regulator_Linear:LP5907MFX-3.3 | SOT-23-5 |
| U102 | AMS1117-3.3 | Regulator_Linear:**AMS1117CD-3.3** | SOT-223 ✓ (назначен) |
| U104 | TPS60400 | Regulator_SwitchedCapacitor:TPS60400DBV | SOT-23-5 |
| L101 | 47мкГн (+5V_A фильтр) | Device:L | Bourns SRN3015-470M |
| L102 | 47мкГн (−5V_A фильтр) | Device:L | Bourns SRN3015-470M |
| L103 | 100мкГн (+5V_HV фильтр) | Device:L | Bourns SRU5028-101Y |
| C101 | 10мкФ тант. | Device:CP | +5V_A фильтр |
| C102 | 100нФ | Device:C | +5V_A фильтр |
| C103 | 1мкФ | Device:C | LP5907 вход |
| C104 | 10мкФ тант. | Device:CP | AMS1117 вход |
| C105 | 10мкФ тант. | Device:CP | AMS1117 выход (**критично**: тантал, не керамика!) |
| C106 | 4.7мкФ | Device:C | LP5907 выход |
| C107 | 100нФ | Device:C | AMS1117 выход ВЧ |
| C108 | 100нФ X7R | Device:C | LP5907 выход доп. bypass |
| C109 | 100нФ | Device:C | FT231XQ 3V3OUT bypass |
| C110 | 100нФ X7R | Device:C | TPS60400 VIN bypass (**X7R обязательно**) |
| C111 | 100нФ X7R | Device:C | TPS60400 CFLY (**X7R обязательно**). ⚠ **НЕ менять на 1 мкФ из даташита** без стабилизатора: 0.1 мкФ даёт Ro инвертора ~50 Ом (вместо 12) → −5V_A ≈ −3.6…−4.1 В на токе ADA4817 19 мА → размах питания ADA4817 8.2–9.2 В при USB 4.75–5.25 В (рабочий макс. 10 В). С 1 мкФ при 5.25 В размах ≈ 10 В — на границе (расчёт 2026-09-19, divider_board.md) |
| C112 | 10мкФ тант. | Device:CP | TPS60400 выход (**полярность обратная**: + к GND) |
| C113 | 10мкФ тант. | Device:CP | −5V_A фильтр (**полярность обратная**: + к GND) |
| C114 | 100нФ | Device:C | −5V_A фильтр |
| C115 | 47мкФ X5R | Device:C | +5V_HV bulk |
| C116 | 100нФ | Device:C | +5V_HV bypass |
| R101 | 330Ом | Device:R | LED D101 (CBUS0 → синий) |
| R102 | 330Ом | Device:R | LED D102 (статус → зелёный) |
| R_CC101 | 5.1кОм | Device:R | USB-C CC1 → GND |
| R_CC102 | 5.1кОм | Device:R | USB-C CC2 → GND |
| D101 | LED синий | Device:LED | USB активность, от FT231XQ CBUS0 |
| D102 | LED зелёный | Device:LED | Статус, управление от MCU (global label LED) |

---

## 1. Входная цепь USB-C

```
USB-C J1 (JAE DX07S024WJ3R400)
  VBUS ──── F1 (500мА PTC) ──── +5V_USB
  D+   ──── U_ESD ────────────── FT231XS PIN14 (D+)
  D-   ──── U_ESD ────────────── FT231XS PIN13 (D-)
  GND  ──── GND
  CC1/CC2 ── 5.1кОм ── GND     (детектирует устройство, не зарядник — 5V 500мА)
```

**Компоненты:**
- **J1**: JAE DX07S024WJ3R400 — USB-C вертикальный SMD, монтаж в центре платы
- **F1**: Bourns MF-MSMF050-2 — PTC 500мА самовосстанавливающийся предохранитель
- **U_ESD**: PRTR5V0U2X (SOT143B, 4 вывода) — двойной rail-to-rail ESD-массив на D+/D− (даташит `docs/refs/PRTR5V0U2X-1320589.pdf`)
- **R_CC101, R_CC102**: 5.1 кОм 0402 × 2 — идентификация USB device (не Host/PD)

**Подключение пинов J1 (DX07S024WJ3R400):**

| Пины J1 | Сигнал | Куда |
|---|---|---|
| A4, A9, B4, B9 | VBUS | → F1 → +5V_USB |
| A1, A12, B1, B12 | GND | GND |
| 25, 26, 27, 28 | SHIELD | GND |
| A5 | CC1 | R_CC1 → GND |
| B5 | CC2 | R_CC2 → GND |
| A6, B6 | D+ | net D_P → U_ESD I/O1 (пин 2) |
| A7, B7 | D− | net D_N → U_ESD I/O2 (пин 3) |
| A8, B8 | SBU1/2 | No Connect |
| A2,A3,A10,A11,B2,B3,B10,B11 | SuperSpeed TX/RX | No Connect |

---

## 2. Шина +5V_A — LC-фильтр

BLM18 феррит имеет ~8 Ом на 250–500 кГц → недостаточно для AD8000.
Используем LC фильтр, идентичный −5V_A: 81 дБ подавления на 250 кГц.

```
+5V_USB ── L1/L101 (47мкГн) ──┬── +5V_A
                               ├── C3/C101 10мкФ тант. ── GND
                               └── C4/C102 100нФ X7R  ── GND
```

**Компоненты:**
- **L1 (KiCad: L101)**: Bourns SRN3015-470M — 47 мкГн, 400 мА, ±20%, DCR 1.4 Ом, экранированный 3.0×3.0×1.5 мм
- **C3 (KiCad: C101)**: 10 мкФ тант., 10В, 0805
- **C4 (KiCad: C102)**: 100 нФ X7R 0402

**Расчёт:**
- f_c = 1/(2π√(47мкГн × 10мкФ)) = **73 Гц**
- Ослабление на 300 кГц: (300000/73)² = **15600×** = **84 дБ**
- USB ripple 50 мВ → +5V_A ripple **< 0.003 мВ** → AD8000 вход < 0.2 мкВ ✓
- Просадка на DCR: 30 мА × 1.8 Ом = **54 мВ** → +5V_A = 4.946 В (AD8000 Vin_min = 4.5В ✓)

---

## 3. +3.3V_A — LP5907MFX-3.3 (аналоговое питание)

```
+5V_USB ─── C5/C103 1мкФ ─── [LP5907 IN] ─── [LP5907 OUT] ─── +3.3V_A
                                    │                  │
                                   GND       C6/C106 4.7мкФ ── GND
                                             C7/C108 100нФ  ── GND
```

**Компонент:** LP5907MFX-3.3/NOPB (SOT-23-5)
- Шум: **6.8 мкВ rms** (10Гц–100кГц) — лучший в классе для VDDA / TL431DBZ (U301)
- PSRR: 79 дБ @ 1 кГц
- Dropout: 90 мВ @ 150 мА → Vin_min = 3.39 В, от 5В — огромный запас
- Ток до 250 мА (нам нужно ~50 мА)

**Пины LP5907MFX-3.3 (SOT-23-5, DBV):**

| Пин | Имя | Куда |
|---|---|---|
| 1 | IN | +5V_USB + C5 → GND |
| 2 | GND | GND |
| 3 | EN | +5V_USB (pull high = всегда включён) |
| 4 | N/C | No Connect (**не NR** — NR пин отсутствует в SOT-23) |
| 5 | OUT | +3.3V_A + C6 ‖ C7 → GND |

**Компоненты обвязки:**
- **C5 (KiCad: C103)**: 1 мкФ X5R 0402, 10В (вход)
- **C6 (KiCad: C106)**: 4.7 мкФ X5R 0402, 10В (выход, параллельно C7)
- **C7 (KiCad: C108)**: 100 нФ X7R 0402 (ВЧ развязка, параллельно C6)

---

## 4. +3.3V_D — AMS1117-3.3 (цифровое питание)

```
+5V_USB ─── C8/C104 10мкФ тант. ─── [AMS1117 IN] ─── [AMS1117 OUT] ─── +3.3V_D
                                           │                   │
                                          GND        C9/C105 10мкФ тант. ── GND
                                                      C10/C107 100нФ X7R  ── GND
```

**Компонент:** AMS1117-3.3 (SOT-223)

> **KiCad символ:** `Regulator_Linear:AMS1117CD-3.3` (TO-252). Footprint `Package_TO_SOT_SMD:SOT-223-3_TabPin2` ✓ назначен.

**Пины AMS1117CD-3.3 (в KiCad символе):**

| Пин | Имя | Куда |
|---|---|---|
| 3 | VI | +5V_USB + C8 → GND |
| 2 | VO | +3.3V_D + C9 ‖ C10 → GND |
| 1 | GND | GND |

**⚠ Внимание:** AMS1117 требует ESR на выходе 0.01–1 Ом для устойчивости.  
С чисто керамическими конденсаторами — возможна генерация!  
→ Обязательно: **10 мкФ танталовый** на входе и выходе.

- Dropout: 1.1 В @ 800 мА → Vin_min = 4.4 В, от 5В — запас 600 мВ ✓
- Рассеиваемая мощность: (5 − 3.3) × 0.15 А = **0.26 Вт** → SOT-223 нормально (θja = 80°C/W → ΔT = 21°C ✓)

**Компоненты обвязки:**
- **C8 (KiCad: C104)**: 10 мкФ танталовый, 10В, 0805 (вход)
- **C9 (KiCad: C105)**: 10 мкФ танталовый, 10В, 0805 (выход — критично для стабильности!)
- **C10 (KiCad: C107)**: 100 нФ X7R 0402 (ВЧ развязка)

---

## 5. −5V_A — TPS60400 + LC-фильтр

### 5.1 Схема TPS60400

**Пины TPS60400DBV (SOT-23-5, KiCad символ):**

| Пин | Имя KiCad | Куда |
|---|---|---|
| 2 | IN | +5V_A + C12/C110 (100нФ bypass) → GND |
| 4 | GND | GND |
| 5 | CFLY+ | один конец C11/C111 (летающий конд.) |
| 3 | CFLY− | другой конец C11/C111 (летающий конд.) |
| 1 | OUT | C13/C112 (10мкФ тант.) → GND; далее → L2/L102 → −5V_A |

```
+5V_A ─── IN(2) [TPS60400] OUT(1) ─── C13/C112 10мкФ тант. ─── GND
                 CFLY+(5) ── C11/C111 100нФ ── CFLY−(3)
                 GND(4) ─── GND
OUT(1) ─── L2/L102 47мкГн ─── −5V_A
```

**Компонент:** TPS60400DBVT (SOT-23-5)
- C11 **(KiCad: C111)** (летающий): **100 нФ X7R 0402** между CFLY+ и CFLY− (критично! X7R, не Y5V)
- C12 **(KiCad: C110)** (bypass VIN): **100 нФ X7R 0402**
- C13 **(KiCad: C112)** (выходной): **10 мкФ танталовый**, полярность обратная (+ к GND)
- f_sw = 250 кГц

### 5.2 LC-фильтр на выходе −5V

**Почему LC, а не феррит:**  
BLM18 феррит имеет сопротивление ~5 Ом на 250 кГц → слабое ослабление.  
LC-фильтр даёт:  f_c = 1/(2π√LC) = 73 Гц → ослабление на 250 кГц = **81 дБ**.

```
−VOUT_raw ── L2/L102 47мкГн ──┬── −5V_A
                               ├── C14/C113 10мкФ тант. ── GND
                               └── C15/C114 100нФ X7R  ── GND
```

**Расчёт:**
- L2/L102 = 47 мкГн, C14/C113 = 10 мкФ → f_c = 73 Гц
- На 250 кГц: затухание = (250000/73)² = **11740×** = **81 дБ**
- Пульсации 25 мВ → после фильтра: **< 0.01 мВ** на −5V_A
- AD8000 PSRR@250кГц = 35 дБ → на вход < 0.3 мкВ → пренебрежимо ✓

**Компоненты:**
- **L2 (KiCad: L102)**: Bourns SRN3015-470M — 47 мкГн, 400 мА, экран, 3.0×3.0×1.5 мм, footprint Neosid SMS-ME3015
- **C14 (KiCad: C113)**: 10 мкФ тант., 16В, 0805 — **полярность обратная** (+ к GND, − к −5V_A)
- **C15 (KiCad: C114)**: 100 нФ X7R 0402

> ⚠ **Полярность на −5V:** C13/C112 и C14/C113 — танталовые конденсаторы на отрицательной шине. Плюс подключается к GND (0В), минус к −5В. На схеме и при пайке обязательно проверить.

---

## 6. Шина +5V_HV — фильтр + транзит на плату ВВ

Шина **+5V_HV** передаёт отфильтрованный +5V_USB на плату ВВ через header.  
Фильтр размещён здесь (а не на HV board) — чтобы помехи от MAX1847 @ 252 кГц не попадали обратно в +5V_USB шину.

```
+5V_USB ── L3/L103 100мкГн ──┬── pin 24 header (+5V_HV) ──→ HV board [MAX1847 VIN]
                              ├── C19/C115 47мкФ X5R ── GND
                              └── C20/C116 100нФ X7R ── GND
```

**Компоненты:**
- **L3 (KiCad: L103)**: Bourns SRU5028-101Y — 100 мкГн, 470 мА, экран, DCR 625 мОм, 5.2×5.2×2.8 мм
- **C19 (KiCad: C115)**: 47 мкФ X7R 10В, 1210 (GRM32ER71A476KE15L, Murata — общий с C206 на HV board); при DC 5В эффективная ёмкость ~33 мкФ
- **C20 (KiCad: C116)**: 100 нФ X7R 0402

**Расчёт подавления @ 252 кГц:**
- f_c = 1/(2π√(100мкГн × 33мкФ)) ≈ **88 Гц**
- Затухание на 252 кГц: (252000/88)² ≈ **8.2×10⁶** = **138 дБ**

**Бюджет тока +5V_HV:**  
MAX1847 + IRLML0040 + CW-умножитель: **~112 мА** @ 5В (typ при U_HV = 1200 В, I_det = 50 нА)  
Просадка на L3 (DCR ≈ 2 Ом): 112 мА × 2 Ом = **224 мВ** → +5V_HV = 4.78 В (MAX1847 Vin_min = 4.5 В ✓)

---

## 7. FT231XS — USB-UART мост

> **KiCad символ:** `Interface_USB:FT231XQ` (QFN-20). Чип FT231XQ — версия QFN-20. Footprint `Package_DFN_QFN:QFN-20-1EP_4x4mm_P0.5mm_EP2.5x2.5mm` ✓ назначен.

**Пины FT231XQ (QFN-20) и подключение:**

| Пин | Имя | Куда |
|---|---|---|
| 12 | VCC | +3.3V_D (bypass: общие C105/C107 на шине) |
| 20 | VCCIO | +3.3V_D (bypass: общие C105/C107 на шине) |
| 10 | 3V3OUT | C18/C109 100нФ → GND (только развязка) |
| 3, 13, 21 | GND | GND |
| 11 | RESET | +3.3V_D (pull high = всегда активен) |
| 8 | USBDP (D+) | net D_P ← от U_ESD I/O2 |
| 9 | USBDM (D−) | net D_N ← от U_ESD I/O1 |
| 17 | TXD | global label UART_TX (→ MCU RX) |
| 1 | RXD | global label UART_RX (← MCU TX) |
| 15 | CBUS0 | R1/R101 (330Ом) → D5/D101 (LED синий) → GND |
| 19,6,18,4,5,2 | RTS,CTS,DTR,DSR,DCD,RI | No Connect |
| 14,7,16 | CBUS1,CBUS2,CBUS3 | No Connect |

**Конфигурация (EEPROM, FT_PROG):**
- Внутренний генератор: включён (кварц не нужен)
- CBUS0: TXLED (индикация USB трафика)
- Baudrate: 600000 (STM32 shproto)
- USB descriptor: "Gamma Spectrometer v1"

**Компоненты:**
- **C18 (KiCad: C109)**: 100 нФ X7R 0402 (3V3OUT bypass)
- C16, C17 не размещены — FT231 VCC/VCCIO питается от +3.3V_D; bypass: общие C105/C107
- **R1 (KiCad: R102)**: 330 Ом 0402
- **D5 (KiCad: D101)**: LED синий 0402 (Würth 150040BS73240)

---

## 8. Индикация (LED D102/D2, D101/D5)

**D2 — статус (зелёный), управление от MCU:**
```
global label LED ── R2/R102 (330Ом) ── D2/D102 anode ── D2/D102 cathode ── GND
```
- Активный высокий (MCU HIGH → LED светится)
- Состояния кодируются паттернами мигания в прошивке
- Управляющий сигнал: global label `LED` → MCU GPIO PB6

| LED | Цвет | Сигнал | MPN (0402) |
|---|---|---|---|
| D2 (KiCad: D102) | Зелёный | global label LED | Würth 150040GS73240 |
| D5 (KiCad: D101) | Синий | FT231XQ CBUS0 | Würth 150040BS73240 |

**D5 — USB активность (синий), от FT231XQ CBUS0:**
```
FT231XQ CBUS0 (пин 15) ── R1/R101 (330Ом) ── D5/D101 anode ── D5/D101 cathode ── GND
```
- Не требует прошивки, управляется FT231XQ аппаратно
- Настройка через FT_PROG: CBUS0 = TXLED

Резисторы R1/R101, R2/R102: 330 Ом 0402 (ток ~10 мА @ 3.3В).

---

## 9. Итоговый BOM

| Ref (KiCad) | Компонент | MPN | Кол. | ~Цена |
|---|---|---|---|---|
| U103 | FT231XQ | FT231XQ (QFN-20) | 1 | $1.70 |
| U101 | LP5907MFX-3.3 | LP5907MFX-3.3/NOPB | 1 | $0.80 |
| U102 | AMS1117-3.3 (символ AMS1117CD-3.3) | AMS1117-3.3 (SOT-223) | 1 | $0.20 |
| U104 | TPS60400 | TPS60400DBVT | 1 | $1.50 |
| U_ESD101 | ESD защита | PRTR5V0U2X | 1 | $0.30 |
| J101 | USB-C верт. SMD | JAE DX07S024WJ3R400 | 1 | $0.60 |
| — | 2×N header (уточняется при разводке) | — | 1 | — |
| F101 | PTC 500мА | MF-MSMF050-2 | 1 | $0.20 |
| L101, L102 | Дроссель 47мкГн (+5V_A, −5V_A) | Bourns SRN3015-470M | 2 | $0.60 |
| L103 | Дроссель 100мкГн (+5V_HV) | Bourns SRU5028-101Y | 1 | $0.50 |
| C115 | 47мкФ X7R 10В 1210 (+5V_HV bulk) | GRM32ER71A476KE15L (Murata) | 1 | $0.25 |
| C116 | 100нФ X7R 0402 (+5V_HV bypass) | — | 1 | $0.02 |
| D102 | LED зелёный 0402 (статус, от MCU) | Würth 150040GS73240 | 1 | $0.05 |
| D101 | LED синий 0402 (FT231XS CBUS0) | Würth 150040BS73240 | 1 | $0.05 |
| R_CC101, R_CC102 | 5.1кОм 0402 | — | 2 | $0.02 |
| R101, R102 | Резисторы 330Ом 0402 | — | 2 | $0.02 |
| C тант. ×5 (C101,C104,C105,C112,C113) | 10мкФ 10В Low ESR | TR3B106K010C0750 (Vishay) | 5 | $1.50 |
| C керам. ×11 (C102,C103,C106-C111,C114,C116) | 100нФ/1мкФ/4.7мкФ X5R/X7R | — | 11 | $0.20 |
| **Итого** | | | | **~$7.30** |

---

## 10. Ключевые проверки перед разводкой

- [ ] C105 (AMS1117 выход, old C9) — танталовый, не керамический
- [ ] C111(CFLY), C110(VIN) (TPS60400 насос, old C11/C12) — X7R, не Y5V/Z5U
- [ ] L101, L102 (47 мкГн, old L1/L2) — ток насыщения > 100 мА (SRN3015-470M: 400 мА ✓)
- [ ] R_CC101/R_CC102 = 5.1 кОм — иначе USB-C хост не даст 5В
- [ ] +3.3V_A и +3.3V_D — **раздельные трассы** от разъёма J2 до потребителей
- [ ] −5V_A трасса — короткая, конденсаторы LC фильтра рядом с TPS60400
- [ ] Pin 24 header = **+5V_HV** → через L103+C115+C116 фильтр (не напрямую с +5V_USB)
- [ ] L103 (100мкГн, old L3) — ток насыщения > 200 мА (SRU5028-101Y: 470 мА ✓)

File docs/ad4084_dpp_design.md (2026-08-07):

# AD4084 — анализ для DPP-версии спектрометра

> ## ⛔ ТЗ УСТАРЕЛО — требует пересмотра перед началом работ над v2
>
> Документ писался 2026-06-10 и целиком стоит на архитектуре, которой больше нет:
> - «PMT анод → **AD8000 ×(−15)**, Divider board **БЕЗ ИЗМЕНЕНИЙ**» — делитель как раз
>   пересобран 2026-06-24: вход теперь **TIA на ADA4817-1ARDZ** (Zt=499 Ω), AD8000 снят.
> - «AD8000 даёт импульсы **В МИНУС**, `amplitude = baseline − min` (как в v1)» — полярность
>   опровергнута 2026-08-07: импульс идёт **ВВЕРХ**, `amplitude = sample − baseline`.
>   Весь расчёт сдвига baseline (резистор `R_inj` от −5V_A) построен на неверном знаке.
> - «Выигрыш ×25 против нашего TL431 (50 → 2 ppm/°C)» — база сравнения теперь
>   **REF35250, 12 ppm/°C**, то есть выигрыш **×6**.
> - «4 слоя сохраняются» — v1 переведена на 2 слоя.
>
> Техническая часть про сам AD4084 (даташит, интерфейс, DPP) остаётся валидной.

> Дата: 2026-06-10. Источник: `docs/refs/ad4084.pdf` (Rev 0, 07/2025, 94 стр.) — прочитан детально.
> **РЕШЕНИЕ ПРИНЯТО (2026-06-10): делаем v1 (аналоговый CR-RC² + G474 ADC). v2 на AD4084 — апгрейд на будущее.**
> Этот документ — готовое ТЗ для MCU board v2.0, когда придёт время: AD4084 обрастёт errata, ценой и наличием.
> Совместимость: v2 = замена ТОЛЬКО MCU board в стеке, межплатные разъёмы те же; Divider/USB/HV board не трогаются (на Divider добавится 1 резистор R_inj для сдвига baseline).

---

## 1. Ключевые факты из даташита

### Общее
- 16-bit SAR, 1.25–20 MSPS, SINAD 92.5 dB @ 1 кГц, SNR 92.4 dB @ 1 МГц
- Транзишн-шум 0.52 LSB rms; INL ±6 ppm; BW входа 272 МГц
- Потребление 66.8 мВт @ 20 MSPS (динамическое)
- Корпус: **BGA-49, 5×5 мм, шаг 0.65 мм** ⚠ (горячий воздух / заводская сборка)
- Spectroscopy явно указана в Applications

### Питание (3-4 домена!)
- **VDD33 = 3.3В** (аналоговый) — от нашей +3.3V_A
- **VDD11 = 1.1В** (ядро), **IOVDD = 1.1В** (интерфейс)
- Вариант А: внутренние LDO — подать **VDDLDO = 1.4–2.7В**, VDD11/IOVDD генерируются сами. ⚠ Внешняя нагрузка на внутренние LDO **запрещена** (нельзя запитать от них трансляторы).
- Вариант Б: внешний 1.1В LDO на VDD11 + IOVDD (VDDLDO не подключать) — **наш выбор**, т.к. от этой же шины питаются уровневые трансляторы.
- Все развязочные конденсаторы **встроены в корпус** (470нФ VDD33, 1.88мкФ VDD11, 220нФ IOVDD/VDDLDO).
- Sequencing: VDD11/IOVDD → VDD33 → цифровые входы → REFIN. После сброса 300 мкс до доступа.

### 🔴 Критическое ограничение №1: уровни интерфейса 1.1В
- Все data-interface пины (DCLK, DCS, SDOB, GPIO0-3) — домен IOVDD (1.045–1.26В максимум!)
- Config SPI входы (CS, SCLK, SDI, CNV) толерантны до 2.5В — **но НЕ 3.3В**
- Выходы качаются 0–IOVDD (1.1В) — STM32 на 3.3В их не прочитает (VIH ≈ 1.87В)
- **Вывод: нужны двунаправленные уровневые трансляторы 3.3В↔1.1В** (например 2× TXU0104/SN74AXC4T245) + LDO 1.1В

### 🔴 Критическое ограничение №2: SPI = только FIFO
- Стр. 67: *"Continuous access to filtered data results is available only through the LVDS data interface. SPI data interface access to filtered results is only made via the FIFO."*
- Непрерывный поток 20 MSPS доступен **только по LVDS** (FPGA/H7-территория)
- **С STM32G474 единственный режим — событийный захват пачками через FIFO** (что нам и нужно)

### Reference
- REFIN требует **внешний прецизионный 3.0В источник** (допуск ±5 мВ!): LTC6655-3.0 (лучший, 2 ppm/°C), **ADR4530B** (0.02%, 2 ppm/°C, дешевле) или LT6657
- Внутри — буфер с 9.4 мкФ резервуаром (буферный усилитель не нужен)
- Это **заменяет и превосходит** наш TL431 (50 ppm/°C → 2 ppm/°C, ×25 лучше температурная стабильность шкалы!)

### Вход
- Полностью дифференциальный: FS = ±V_REFIN = ±3В дифф. (6 Vpp), LSB = 91.55 мкВ
- CM = 1.5В задаётся выходом **CMO** (V_REFIN/2, импеданс 700Ом, фильтровать RC)
- Easy Drive: ток входа 5 мкА/MSPS линеаризованный → драйвер маломощный достаточен
- Анти-алиас фильтр (Table 8, 20 MSPS/16бит): **R_FILTIN=25Ом, C_FILTIN=100пФ** (дифф.), AUXIN: R=100Ом, C=25пФ
- AUXIN+/− — вспомогательные входы линеаризации, подключаются к тому же сигналу через 4×R
- Рекомендуемые драйверы (Table 12): **ADA4945-1** (FDA, 4мА, 1.8нВ/√Гц, 145МГц — lowest power) ← наш выбор

### Event Detection (стр. 53-55) — аппаратный триггер импульсов!
- HI_THRESHOLD/LO_THRESHOLD (регистры 0x21-0x24) сравниваются с каждым сэмплом
- Гистерезис настраиваемый (0x1F)
- Латентность: **t_EVT = 2–3 цикла CNV** (100–150 нс @ 20 MSPS) от пересечения порога до ALERT
- ALERT/HI_DTCT можно вывести на GPIO → EXTI на MCU
- Событие может **аппаратно запускать FIFO**

### Result FIFO (16384 × 16 бит, стр. 55-62)
| FIFO_MODE | Режим | Применение |
|---|---|---|
| 00 | выключен | — |
| 01 | Immediate trigger | захват N=WATERMARK сразу (для baseline-замеров) |
| **10** | **Event trigger, post-event** | **захват WATERMARK сэмплов ПОСЛЕ события — наш основной режим** |
| 11 | Event trigger, read all 16K | пред+пост история, но читать все 16384 (6 мс — слишком медленно) |

- Статусы FIFO_FULL / FIFO_READ_DONE → на GPIO
- После захвата FIFO надо перевооружить (запись по config SPI: MODE=00 → MODE=10)
- Чтение: header + M×байт по data SPI (DCS/DCLK/SDOB), DCLK до 50 МГц, 1 или 4 линии

### Цифровые фильтры (Sinc1/Sinc5/Sinc5+comp, decimation 2–1024)
- Работают на полном потоке, выход можно подавать на event detection и FIFO
- ⚠ С FIFO требуют FILTER_SYNC (GPIO) перед каждым захватом — усложнение
- **Решение: фильтр НЕ используем** (FILTER_SEL=00), сырые 20 MSPS сэмплы в FIFO, фильтрация в MCU на пачке

### Коррекции в чипе
- OFFSET регистр: ±2048 LSB (±11.7 мВ)
- GAIN регистр: ±1.56% FS, шаг 0.003% — для подстройки тракта, **недостаточен для термокомпенсации PMT** (нужно до ±24%) → термокомпенсация остаётся в MCU (математика) и/или через HV

---

## 2. Предлагаемая архитектура (G474 + AD4084, Figure 51 из даташита)

```
PMT анод → AD8000 ×(−15) [Divider board — БЕЗ ИЗМЕНЕНИЙ] → коаксиал U.FL →
[MCU board v2.0]:
  ADA4945-1 (FDA, SE→diff, gain ≈1.3, VOCM=CMO 1.5В, питание +5V_A)
  → анти-алиас 25Ом/100пФ дифф. (+ AUXIN цепь 100Ом/25пФ)
  → AD4084 @ ~17 MSPS (CNV от TIM STM32 через транслятор)
  → Event Detection (порог чуть выше baseline) → GPIO → EXTI G474
  → FIFO mode 10, WATERMARK = 48 (2.8 мкс окно)
  → G474 читает пачку по SPI+DMA (42.5 МГц) → DSP → гистограмма 8192 → shproto
```

### 2.1. Драйвер: нужен ли ADA4945 при живом AD8000?

AD8000 (1.5 ГГц CFA на делителе) способен раскачать входы AD4084 напрямую — Easy Drive входы (5 мкА/MSPS линеаризованные) и анти-алиас 25Ом/100пФ для него лёгкая нагрузка.

**Препятствие — полярность/диапазон:** AD8000 даёт импульсы В МИНУС (baseline 0В → −2.28В @ 3.5 МэВ), а вход AD4084 допускает только −0.1…+3.1В.

**Вариант А — прямое подключение (без FDA):**
- Сдвиг baseline: инжекция тока в инвертирующий вход AD8000 от −5V_A через R_inj ≈ 2.7к → baseline = +2.8В, импульсы вниз до +0.52В ✓ (**+1 резистор на Divider board**)
- IN+ ← сигнал; IN− ← DC от CMO (RC-фильтрованный); AUXIN± аналогично через 100Ом
- Event detection по **LO_THRESHOLD** (импульсы вниз); прошивка: `amplitude = baseline − min` (как в v1)
- Минус: single-ended = половина дифф. диапазона → **15 эфф. бит**. Но шум тракта ~110 мкВ ≈ 1.2 LSB — квантование не лимитирует, потеря бита ничего не стоит
- Шум −5V_A через R_inj: вклад ≈0.25 нВ/√Гц на вход — пренебрежимо (LC-фильтр 81 дБ уже стоит)

**Вариант Б — ADA4945-1 FDA на MCU board:**
- Полный диапазон (16 бит), инверсия в плюс, CM от CMO по канону ADI, изоляция кикбэка от коаксиала
- +$4, +1 корпус

**Решение для v2-платы: развести footprint ADA4945 с обходом 0Ω перемычками.** Прототип собирать по варианту А; FDA — запасной вариант без перерезки платы.

### Расчёт мёртвого времени (FIFO mode 10)
- Окно 48 сэмплов × 2 байта ≈ 100 байт @ 42.5 Мбит/с ≈ 19 мкс чтение
- Перевооружение: config SPI запись ~1 мкс + 2-3 CNV
- **Итого ~20-25 мкс/импульс**: 1 kcps → 2.5% dead time ✓; 10 kcps → 25% ⚠; 30 kcps → не работает ✗
- Для пищевого/экологического мониторинга (≤1 kcps) — отлично

### Захват пика при латентности триггера 100-150 нс
- Анти-алиас RC + замедление фронта: порог на ~15% амплитуды → пик через 300-400 нс после пересечения → захват стартует до пика ✓
- Baseline: отдельные периодические immediate-захваты (mode 01) между импульсами + цифровое слежение

### Порог обнаружения
- Шум тракта на входе AD4084 (10 МГц полоса): ~110 мкВ rms → 5σ ≈ 0.6 мВ ≈ **<1 кэВ** даже на сырых сэмплах ✓

---

## 3. Список изменений по платам

### Divider board — БЕЗ ИЗМЕНЕНИЙ ✓
AD8000 остаётся как есть.

### USB/Power board — без изменений (бюджет тока +30 мА: 370→400 мА < 500 ✓)

### HV board — без изменений

### MCU board → v2.0 (КРУПНЫЙ REDESIGN)
**Удаляется:**
- Весь аналоговый шейпер: R305/306/308/309, C314-C318 (OPAMP1/2/3 больше не используются)
- DC-делители A/B: R310-R313, C320, C321
- U301 TL431 (заменён ADR4530)
- Test pulse цепь возможно упростить (DAC → FDA вход)

**Добавляется:**
| Компонент | Назначение | ~Цена |
|---|---|---|
| AD4084BBCZ (BGA-49) | АЦП 16-bit 20 MSPS | $40-60? (Rev 0, цена не устоялась) |
| ADA4945-1CPZ (LFCSP-16) | FDA драйвер SE→diff | $4 |
| ADR4530BRZ (SOIC-8) | 3.0В reference, 2 ppm/°C | $4 |
| LDO 1.1В (NCP163AFCT110 / TLV74011) | VDD11+IOVDD+трансляторы | $0.5 |
| 2× транслятор уровней (TXU0104 / SN74AXC4T245) | 3.3↔1.1В: CNV,CS,SCLK,SDI,DCS,DCLK вниз; SDOB,GPIO0-3 вверх | $3 |
| Анти-алиас: 25Ом×2, 100Ом×2, 100пФ, 25пФ×2, RC на CMO | пассивы | $0.5 |

**Пины G474 освобождаются:** PA1-PA7, PB0-PB2 (OPAMP/DAC цепи) → используются под второй SPI (data) + GPIO (ALERT/FIFO_FULL/FIFO_READ_DONE EXTI) + TIM CNV.

**PCB:** 4 слоя сохраняются (LVDS не нужен — SPI). BGA 0.65мм dogbone: JLCPCB 4-layer справляется (0.2мм сверло / 3.5mil трасса), но желательна заводская сборка этого узла.

### Прошивка
- + Драйвер AD4084 (config SPI: ~15 регистров init)
- + FSM: ARM → EXTI(event) → DMA read FIFO → DSP → re-arm
- + DSP на пачке 48 сэмплов: baseline-вычитание, цифровой фильтр/фит пика, PUR по форме
- Гистограмма/shproto/термокомпенсация — без изменений (16-битная амплитуда >> 3 → 8192 каналов)
- Симуляции: sim2 (CR-RC²) → не нужна; вместо неё Python-моделирование цифрового фильтра; sim3 пересчитать на новый тракт

---

## 4. Что даёт и чего НЕ даёт

### Даёт
1. **Шкала стабильнее ×25**: ADR4530 2 ppm/°C vs TL431 50 ppm/°C (термодрейф электроники практически исчезает; остаётся только PMT+кристалл)
2. **16 бит честных**: Am-241 59.5 кэВ ≈ 820 LSB (vs 51 LSB на 12-бит) → можно расширить диапазон вниз до рентгеновской области 10-20 кэВ (Np L-линии, Pb флуоресценция)
3. **Полная форма импульса 20 MSPS** → PSD (n/γ дискриминация с CLYC/стильбеном в будущем), rise-time PUR
4. **Software-defined shaping** → LaBr3 (τ=25нс) без переделки железа
5. Минус 15 пассивов аналогового шейпера и их разброс/дрейф

### НЕ даёт
1. **FWHM на NaI+R1307 НЕ улучшится**: 6.3% статистики ФЭУ доминируют (наша электроника уже 0.064%)
2. **Высокий CPS НЕ получится через SPI**: мёртвое время чтения FIFO ограничивает ~5-10 kcps практических (vs 30 kcps у аналогового тракта с G474 ADC)  ← парадокс: DPP-версия на SPI **хуже по скорости счёта**, чем текущий план!
3. Цена +$50-70, BGA-сборка, Rev 0 риски

---

## 5. Риски
1. **Rev 0 (07/2025)** — errata неизвестны, цена не устоялась, наличие у дистрибьюторов под вопросом
2. **BGA-49 0.65мм** — самостоятельная пайка сложная; план: JLCPCB assembly узла АЦП
3. Сложность инициализации (94 стр., ~15 регистров, sequencing питания)
4. Транслятор уровней в цепи CNV — джиттер (для нашей полосы сигнала ≤1.5 МГц не критичен)

---

## 6. Открытое решение

| | v1: аналоговый CR-RC² (текущий план) | v2: DPP на AD4084 |
|---|---|---|
| Готовность схем | 100% (ERC ✓, BOM ✓) | MCU board redesign ~2-4 недели |
| FWHM @ Cs-137 | 6.0-6.5% | 6.0-6.5% (то же) |
| Макс CPS | ~30 kcps | ~5-10 kcps (SPI-лимит) |
| Порог | ~1 кэВ | <1 кэВ, рентген 10-20 кэВ возможен |
| Темп. стабильность шкалы | TL431 50 ppm/°C + компенсация | ADR4530 2 ppm/°C + компенсация |
| Гибкость (LaBr3, PSD) | нет | да |
| Цена | ~22€ | ~75-90€ |
| Сборка | вся рукой | BGA = заводская сборка узла |
| Риск | минимальный | Rev 0 + BGA |

**Рекомендация Claude:** v1 довести до железа (схемы готовы!), v2 проектировать параллельно как отдельную MCU board v2.0 — стек плат позволяет заменить ОДНУ плату, не трогая USB/HV/Divider. Обе версии MCU board совместимы по межплатным разъёмам.

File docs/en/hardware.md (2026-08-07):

# Hardware Overview

<!-- README-I18N:START -->
[Русский](../ru/hardware.md) | **English**
<!-- README-I18N:END -->

The instrument is a cylindrical stack of four Ø45 mm boards mounted directly
behind a NaI(Tl) Ø63×63 mm scintillator coupled to a Hamamatsu R1307
photomultiplier tube (PMT). A single USB-C cable exits the end cap and carries
both power and data.

## Board Stack (bottom → top)

```
[end cap — USB-C cable]
  1. USB/Power board   Ø45 mm   USB-C (JAE DX07S024WJ3R400)
  2. HV board          Ø45 mm   MAX1847 flyback + 8-stage CW multiplier, 0…−1500 V
  3. MCU board         Ø45 mm   STM32G474, CR-RC² shaper, ADC
  4. Divider board     Ø42–45 mm  R1307 divider + ADA4817 TIA
[end cap — R1307 PMT + NaI(Tl)]
```

### Inter-board connections

| Link | From → To | Connector |
|---|---|---|
| Stack power/control | board ↔ board | 2×N 2.54 mm pin headers |
| Signal | Divider → MCU | RG-178 coax + U.FL |
| Divider analog power | MCU → Divider | JST PH 3-pin (+5V_A, AGND, −5V_A) |
| −HV | HV → Divider | shielded ≥5 kV wire along the stack edge |

## Signal Chain

```
NaI(Tl)+R1307 → ADA4817 TIA (Zt=499Ω) → coax → CR(OPAMP1) → RC(OPAMP2) → PGA×4(OPAMP3) → ADC
[divider board]  ±5V_A          U.FL   τ=1 µs        τ=510 ns      DC=0.41 V       3.3 V
anode ≈ 0 V (virtual gnd)  amp_out = +469 mV @Cs-137  [MCU board — G474]
```

**Polarity:** the ADC pulse goes *up* from the 0.41 V baseline (the PMT anode sinks
current, so the TIA output rises). In DSP: `amplitude = sample − baseline`.

---

## 1. USB/Power board

USB-C interface and all supply rails for the stack.

- **FT231XQ** (QFN-20) — USB ↔ UART bridge at 600 kbps, exposed as a virtual COM port.
- **LP5907** → +3.3V_A (low-noise analog), **AMS1117CD-3.3** → +3.3V_D (digital).
- **TPS60400** charge pump → −5V_A.
- 47 µH LC filters on +5V_A and −5V_A (≈84 dB at 300 kHz).
- **+5V_HV** — raw USB 5 V routed through an LC filter to the HV board.
- **PRTR5V0U2X** ESD protection on the USB data lines.
- USB 2.0 budget ≈ 370 mA < 500 mA.

Detailed schematic: [`docs/usb_power_board_schematic.md`](../usb_power_board_schematic.md) (RU).

## 2. HV board

Generates the regulated negative high voltage for the PMT.

- **MAX1847** flyback controller + **IRLML0040** switch + **ATB322524** transformer (1:10.2).
- 8-stage Cockcroft–Walton (CW) multiplier producing 0 … −1500 V.
- Powered from the raw +5V_HV rail (not from the clean analog rails).
- Output RC filter chain (3×100 kΩ + HV capacitors) for ripple suppression.
- Feedback: CW output → 1 GΩ divider → MAX1847 error amplifier; `V_HV = −V_CTRL × 454.5`.
- Monitoring: 68 MΩ divider + **TL431** reference → `HV_MONITOR` on an MCU ADC pin.
- `HV_ENABLE` is active-high (MCU high = HV on).
- The assembled board is potted in silicone after test.

Detailed schematic: [`docs/hv_board_schematic.md`](../hv_board_schematic.md) (RU).

## 3. MCU board (v1.6)

The signal-processing and interface core.

- **STM32G474MET6** @ 170 MHz with internal **OPAMP1/2/3** and a 12-bit ADC at 4 Msps.
- Input: U.FL connector carrying ~470 mV @Cs-137 from the ADA4817 TIA on the divider board.
- Analog shaper: **CR** (10 kΩ + 100 pF + 10 kΩ) → **RC** (1 kΩ + 510 pF + 1 kΩ),
  forming a CR-RC²-style pulse, followed by a ×4 PGA into the ADC.
- **REF35250** voltage reference (2.500 V, 12 ppm/°C, SOT-23-6) plus DC-bias dividers
  for the ADC baseline. It replaced the TL431DBZ on 2026-08-07 following review.
- **W25Q64** SPI flash, 16 MHz crystal.
- **Pt1000** temperature sensor (Honeywell 700-102BAA-B00) on the crystal housing,
  read ratiometrically for thermal-drift compensation.
- `HV_CONTROL` PWM → RC filter → HV board.

Detailed doc: [`docs/adc_mcu_board.md`](../adc_mcu_board.md) (RU).

## 4. Divider board

Active PMT divider and front-end amplifier, mounted closest to the tube.

- **Hamamatsu R1307-01** (flying leads), 11 pins.
- Resistor chain R401–R412 (tapered for spectrometry) with bypass/storage caps on the
  last dynodes only (C408/C409/C410 = 22/47/100 nF on Dy6–Dy8).
- Three **MMBTA42** transistor buffers (Q401/Q402/Q403) on dynodes Dy6/Dy7/Dy8, biased by
  the divider current (the chain runs through the dynodes via emitter resistors, per
  Hamamatsu Fig 5-15). B–E clamp diodes D401–D403 (1N4148W) protect against reverse
  breakdown on the HV ramp.
- **ADA4817-1ARDZ** transimpedance amplifier (TIA): anode directly on −IN (virtual ground),
  `Rf = 499 Ω`, `Cf = 4.7 pF` (NP0), Zt = 499 Ω, BW ≈ 92 MHz. ~18% lower noise than the
  former AD8000 inverter.
- Powered from ±5V_A delivered over the stack.

Detailed doc: [`docs/divider_board.md`](../divider_board.md) (RU).

---

See [simulations.md](simulations.md) for the analog-chain simulations and the
full noise budget, and [firmware.md](firmware.md) for the digital pulse processing.

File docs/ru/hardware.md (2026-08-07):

# Обзор аппаратной части

<!-- README-I18N:START -->
**Русский** | [English](../en/hardware.md)
<!-- README-I18N:END -->

Прибор — цилиндрический стек из четырёх плат Ø45 мм, установленных прямо за
сцинтиллятором NaI(Tl) Ø63×63 мм, сопряжённым с ФЭУ Hamamatsu R1307. Единственный
кабель USB-C выходит с торца и несёт и питание, и данные.

## Стек плат (снизу → вверх)

```
[торец — кабель USB-C]
  1. USB/Power board   Ø45 мм   USB-C (JAE DX07S024WJ3R400)
  2. HV board          Ø45 мм   MAX1847 flyback + 8-ступ. CW умножитель, 0…−1500 В
  3. MCU board         Ø45 мм   STM32G474, шейпер CR-RC², ADC
  4. Divider board     Ø42–45 мм  делитель R1307 + ADA4817 TIA
[торец — ФЭУ R1307 + NaI(Tl)]
```

### Межплатные соединения

| Связь | Откуда → Куда | Разъём |
|---|---|---|
| Питание/управление стека | плата ↔ плата | pin-header 2×N 2.54 мм |
| Сигнал | делитель → МК | коаксиал RG-178 + U.FL |
| Аналоговое питание делителя | МК → делитель | JST PH 3-пин (+5V_A, AGND, −5V_A) |
| −ВВ | ВВ → делитель | экранированный провод ≥5 кВ вдоль края стека |

## Цепь сигнала

```
NaI(Tl)+R1307 → ADA4817 TIA (Zt=499Ω) → коакс → CR(OPAMP1) → RC(OPAMP2) → PGA×4(OPAMP3) → ADC
[плата делителя] ±5V_A         U.FL   τ=1 мкс       τ=510 нс      DC=0.41 В       3.3 В
анод ≈ 0 В (вирт. земля)  amp_out = +469 мВ @Cs-137   [плата МК — G474]
```

**Полярность:** импульс на АЦП идёт *вверх* от baseline 0.41 В (анод ФЭУ забирает ток,
выход TIA растёт). В DSP: `amplitude = sample − baseline`.

---

## 1. Плата USB/питания

Интерфейс USB-C и все шины питания стека.

- **FT231XQ** (QFN-20) — мост USB ↔ UART на 600 кбит/с, виден как виртуальный COM-порт.
- **LP5907** → +3.3V_A (малошумящий аналог), **AMS1117CD-3.3** → +3.3V_D (цифра).
- Зарядовый насос **TPS60400** → −5V_A.
- LC-фильтры 47 мкГн на +5V_A и −5V_A (≈84 дБ @ 300 кГц).
- **+5V_HV** — сырой USB 5 В через LC-фильтр на плату ВВ.
- ESD-защита **PRTR5V0U2X** на линиях данных USB.
- Бюджет USB 2.0 ≈ 370 мА < 500 мА.

Детальная схема: [`docs/usb_power_board_schematic.md`](../usb_power_board_schematic.md).

## 2. Плата ВВ

Генерирует регулируемое отрицательное высокое напряжение для ФЭУ.

- Контроллер flyback **MAX1847** + ключ **IRLML0040** + трансформатор **ATB322524** (1:10.2).
- 8-ступенчатый умножитель Кокрофта–Уолтона (CW), 0 … −1500 В.
- Питается от сырой шины +5V_HV (не от чистых аналоговых шин).
- Выходной RC-фильтр (3×100 кОм + ВВ-конденсаторы) для подавления пульсаций.
- Обратная связь: выход CW → делитель 1 ГОм → усилитель ошибки MAX1847; `V_HV = −V_CTRL × 454.5`.
- Мониторинг: делитель 68 МОм + опора **TL431** → `HV_MONITOR` на пин АЦП МК.
- `HV_ENABLE` активный HIGH (HIGH от МК = ВВ включено).
- Собранная плата заливается силиконом после проверки.

Детальная схема: [`docs/hv_board_schematic.md`](../hv_board_schematic.md).

## 3. Плата МК (v1.6)

Ядро обработки сигнала и интерфейса.

- **STM32G474MET6** @ 170 МГц со встроенными **OPAMP1/2/3** и 12-бит АЦП на 4 Мвыб/с.
- Вход: разъём U.FL с ~470 мВ @Cs-137 от ADA4817 TIA на плате делителя.
- Аналоговый шейпер: **CR** (10 кОм + 100 пФ + 10 кОм) → **RC** (1 кОм + 510 пФ + 1 кОм),
  формирует импульс типа CR-RC², далее PGA ×4 в АЦП.
- Опора напряжения **REF35250** (2.500 В, 12 ppm/°C, SOT-23-6) плюс делители DC-смещения
  для baseline АЦП. Заменила TL431DBZ 2026-08-07 по итогам ревью.
- SPI-флеш **W25Q64**, кварц 16 МГц.
- Датчик температуры **Pt1000** (Honeywell 700-102BAA-B00) на корпусе кристалла,
  читается ratiometric для термокомпенсации дрейфа.
- `HV_CONTROL` PWM → RC-фильтр → плата ВВ.

Детальный док: [`docs/adc_mcu_board.md`](../adc_mcu_board.md).

## 4. Плата делителя

Активный делитель ФЭУ и входной усилитель, ближе всего к трубке.

- **Hamamatsu R1307-01** (гибкие выводы), 11 пинов.
- Резистивная цепочка R401–R412 (тейпер под спектрометрию); bypass/накопительные капы
  только на последних динодах (C408/C409/C410 = 22/47/100 нФ на Dy6–Dy8).
- Три транзисторных буфера **MMBTA42** (Q401/Q402/Q403) на динодах Dy6/Dy7/Dy8, смещены
  током делителя (цепочка идёт через диноды эмиттерными резисторами, по Hamamatsu Fig 5-15).
  Защитные диоды B–E D401–D403 (1N4148W) — от обратного пробоя на рампе ВВ.
- **ADA4817-1ARDZ** трансимпедансный усилитель (TIA): анод напрямую на −IN (виртуальная
  земля), `Rf = 499 Ом`, `Cf = 4.7 пФ` (NP0), Zt = 499 Ом, полоса ≈ 92 МГц. На ~18% тише
  прежнего AD8000-инвертора.
- Питается от ±5V_A, поданных по стеку.

Детальный док: [`docs/divider_board.md`](../divider_board.md).

---

См. [simulations.md](simulations.md) — симуляции аналогового тракта и полный бюджет
шумов, и [firmware.md](firmware.md) — цифровая обработка импульсов.

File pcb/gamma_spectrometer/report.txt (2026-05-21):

Обновлено +5V_A с #+5V_A0205 в #+5V_A0401.
Обновлено +5V_A с #+5V_A0206 в #+5V_A0402.
Обновлено GND с #PWR0270 в #PWR0401.
Обновлено GND с #PWR0271 в #PWR0402.
Обновлено GND с #PWR0272 в #PWR0403.
Обновлено GND с #PWR0273 в #PWR0404.
Обновлено GND с #PWR0274 в #PWR0405.
Обновлено −5V_A с #−5V_A0204 в #−5V_A0401.
Обновлено 100nF с C256 в C401.
Обновлено 100nF с C257 в C402.
Обновлено 100nF с C258 в C403.
Обновлено 100nF с C259 в C404.
Обновлено 100nF с C260 в C405.
Обновлено 100nF с C261 в C406.
Обновлено 100nF с C262 в C407.
Обновлено 22nF с C263 в C408.
Обновлено 47nF с C264 в C409.
Обновлено 100nF с C265 в C410.
Обновлено 4,7uF с C266 в C411.
Обновлено 100nF с C267 в C412.
Обновлено 4,7uF с C268 в C413.
Обновлено 100nF с C269 в C414.
Обновлено 1pF с C270 в C415.
Обновлено PMT с J_PMT202 в J_PMT401.
Обновлено MMBTA42 с Q203 в Q401.
Обновлено MMBTA42 с Q204 в Q402.
Обновлено MMBTA42 с Q205 в Q403.
Обновлено 750k с R250 в R401.
Обновлено 750k с R251 в R402.
Обновлено 680k с R252 в R403.
Обновлено 680k с R253 в R404.
Обновлено 680k с R254 в R405.
Обновлено 680k с R255 в R406.
Обновлено 680k с R256 в R407.
Обновлено 10k с R257 в R408.
Обновлено 820k с R258 в R409.
Обновлено 1M с R259 в R410.
Обновлено 10k с R260 в R411.
Обновлено 499k с R261 в R412.
Обновлено 10k с R262 в R413.
Обновлено 499k с R263 в R414.
Обновлено R50 с R264 в R415.
Обновлено 100R с R265 в R416.
Обновлено R1.5k с R266 в R417.
Обновлено AD8000YRDZ-REEL с U211 в U401.
Аннотация завершена.
Аннотация завершена.

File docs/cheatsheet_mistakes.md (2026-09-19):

# Шпаргалка: типовые ошибки и правила проверки схем

> **Подгружать при каждой работе с KiCad схемами.**

---

## Правила проверки скриншотов

- Проходить по КАЖДОМУ пину явно: "пин X соединён с Y — совпадает с документацией?"
- Не писать "правильно" до завершения полного обхода всех узлов
- Сверять с даташитом, не только с документацией проекта
- При сомнении — просить пользователя прислать крупный план узла

---

## Ошибки, допущенные в проекте

### 1. Полярность конденсаторов на отрицательной шине

**Правило:** На отрицательной шине (−5V_A, −HV и т.п.) полярные конденсаторы подключаются **НАОБОРОТ**:
- `+` пластина → GND
- `−` пластина → отрицательная шина

**Прецедент:** C112 (TPS60400 выход), C113 (−5V_A фильтр) на USB/Power board — полярность обратная: `+` к GND.

**Проверять:** Любой полярный конденсатор на шинах с отрицательным потенциалом.

---

### 2. BAS516 — снаббер первичной цепи, НЕ выпрямитель вторичной

**Правило:** В flyback на MAX1847+ATB322524:
- BAS516 (**D201**) стоит в **первичной** цепи: Анод → Drain Q201 / T201 pin4
- Катод → снаббер (C208 10нФ ‖ 2×BZT52C18 последовательно → GND)
- На вторичной обмотке (T201 pin3) **нет отдельного диода** — выпрямление выполняют BAV23S внутри CW умножителя

**Прецедент:** Изначально ошибочно планировался BAS516 как выпрямитель вторичной → схему пришлось перерисовывать.

---

### 3. Полярность вторичной обмотки ATB322524

**Правило:** По даташиту ATB322524-0110-T000:
- Pin 1 = начало первичной (dot), Pin 4 = конец первичной
- Pin 2 = начало вторичной (dot), Pin 3 = конец вторичной

**Подключение:**
```
T201 pin 1 → +5V_HV
T201 pin 4 → Drain Q201 (IRLML0060, до 2026-09-19 IRLML0040)
T201 pin 2 (dot) → GND
T201 pin 3 → C209 1нФ (первый конденсатор CW)
```

**Прецедент:** pin2 и pin3 перепутаны местами → неверная полярность выхода → перерисовка.

---

### 4. CS пин MAX1847 — Source до резистора, не после

**Правило:** Q201 Source подключён к CS (pin 13) И к R205 (0.1Ом). CS снимает напряжение на узле Source ДО резистора R205:

```
Q201 Source ─┬─ CS (pin 13 MAX1847)
             ├─ R205 0.1Ом ─── GND
             └─ C205 100пФ ─── GND   (параллельно R205)
```

---

### 5. SHDN MAX1847 — активный HIGH, прямое подключение от MCU

**Правило:** HV **выключено** по умолчанию (безопасное состояние):
- MCU HV_ENABLE = HIGH (3.3В) → SHDN = HIGH → MAX1847 работает → HV включён
- MCU HV_ENABLE = LOW / floating → R203 (100кОм) тянет SHDN к GND → MAX1847 стоп

P-MOSFET AO3415 **не используется** — убран. Схема: MCU → R204(10кОм) → SHDN; R203(100кОм) → GND.
V_IH(SHDN) ≈ 0.7×VL ≈ 3В; MCU 3.3В > 3В ✓

---

### 6. BAV23S в CW умножителе — используется как ОДИН диод

**Правило:** BAV23S содержит два диода последовательно (pin1=A1, pin3=средняя точка, pin2=K2).
В CW умножителе используется как **единый диод повышенного напряжения**:
- **pin1 (A)** → анод
- **pin2 (K)** → катод
- **pin3 → NC (не подключён, висит в воздухе)**

Поставить `X` (No Connect) на pin3 каждого BAV23S в KiCad во избежание ERC ошибки.

**Зачем:** 2 диода последовательно = 2×250В = **500В** обратное напряжение.
В нашем CW на ступень приходится 2×94.6В = 189В << 500В ✓

---

### 7. UART MCU↔FTDI — крест, не прямое соединение

**Правило:** TX одного устройства идёт на RX другого:
- FTDI TXD (выход, пин 17) → **PA10** (USART1_RX, вход MCU) — метка **UART_TX**
- PA9 (USART1_TX, выход MCU) → FTDI RXD (вход, пин 1) — метка **UART_RX**

**Прецедент:** соединили TXD↔PA9 (выход на выход) и RXD↔PA10 (вход на вход) — связь невозможна. ERC не поймал: пины MCU объявлены `bidirectional`. Найдено аудитом нетлиста 2026-06-11.

**Проверять:** в нетлисте у каждой UART-цепи должен быть ровно один `(pintype "output")` и один вход.

---

### 8. Активный делитель ФЭУ (Hamamatsu Fig 5-15): база и эмиттер — РАЗНЫЕ цепи

> **⚠ Переписано 2026-06-24 под фактическую активную топологию.** Прежняя формулировка
> («динод = ТОЛЬКО эмиттер, цепочка НЕ касается динода») описывала ОТКЛЮЧЁННЫЙ старый вариант
> и теперь активно вредна — по новой топологии ток делителя НАМЕРЕННО идёт через диноды.

**Правило (актуальная топология, нетлист 24.06):** у каждого буфера Q401-403 две раздельные цепи:
- **База** ← узел высокоомной базовой нитки (R407→R409→R410→R412), задающей опорное напряжение.
- **Эмиттер** = вывод динода ФЭУ; **коллектор** = следующий (менее отрицательный) динод, у Q403 — GND.
- **Эмиттерный резистор** (R408, DY5→DY6) намеренно соединяет резистивную цепочку с динодной линией:
  ток делителя течёт ЧЕРЕЗ диноды (переходы C→E стэка + R408) и смещает транзисторы в class-A (~96 мкА).

**Анти-паттерн (исходная ошибка):** нельзя вести базовый резистор на узел, который и есть
СОБСТВЕННЫЙ эмиттер транзистора — тогда V_BE=0 навсегда, буфер заперт, делитель работает как
пассивный. База и эмиттер должны быть разными узлами, соприкасаясь только через переход B-E.

**Прецедент:** (1) исходно узел цепочки слит с динодом и эмиттером → база на собственный эмиттер →
V_BE=0, Q401-403 мертвы (аудит нетлиста 2026-06-11). (2) Затем делитель пересобран по Fig 5-15
(ток через диноды) — старое правило «цепочка не касается динода» стало неверным (REVIEW_divider_latest R-2).

**Проверять:** база и эмиттер каждого Qхх — РАЗНЫЕ цепи; Vbe должно быть ≈+0.5…0.6 В (sim/DC),
Ic ≈ десятки–сотни мкА. Если Vbe≈0 — буфер заперт.

---

### 9. Нагрузка на катод TL431 — пересчитывать ток при каждом добавлении

> ⚠ **Для `U301` (опора VREF на плате МК) правило БОЛЬШЕ НЕ ДЕЙСТВУЕТ с 2026-08-07:**
> TL431 заменён на **REF35250** — последовательную опору, которой нагрузка безразлична в пределах
> 10 мА (у нас 0.64 мА). Балластный `R301` удалён. Правило остаётся в силе для **`U202`** на ВВ-плате,
> где TL431 сохранён.

**Правило:** I_KA(min) = 1 мА. Остаток тока на TL431 = I(R_bias) − Σ(нагрузки узла VREF). Держать запас ≥ 1.5 мА.

**Прецедент:** ратиометрическое подключение Pt1000 (R303 на катод U301) добавило 0.225 мА к делителям A/B и VREF+ STM32 → остаток упал до ~0.9-1.1 мА. R301: 470 → **330 Ом**.

---

### 10. РАЗВОДКА: коллектор Q403 (фикс C1) — звёздная земля, отдельно от сигнальной

**Правило:** после фикса C1 коллектор буфера Q403 сидит на **общей GND** и сажает туда самый
большой импульсный динодный ток (пик Dy8 ~0.7 мА). На той же GND — возврат анодного сигнала
(Rin/R415). Трассу коллектора Q403 вести **отдельно к точке-звезде GND**, держа подальше от
сигнального возврата анода; не допускать общего импеданса земли между ними.

**Зачем:** иначе импульс динода через общий импеданс GND подмешается в анодный сигнал →
порча усиления/линейности. Чисто layout-эффект (симуляцией не ловится).

**Прецедент:** REVIEW_round3 R2 (новая находка после фикса C1: Q403.C переведён midP→GND).

---

### 11. AD8000 (и любой ОУ с пином FEEDBACK): Rfb идёт на −IN, НЕ на OUTPUT

**Правило:** у AD8000 пин **FEEDBACK (1) внутри соединён с OUTPUT (6)** — это один узел (даташит «Low Distortion Pinout»). Резистор обратной связи Rfb (и Cfb) ставится **между FB(1) и −IN(2)**, а нагрузка (U.FL, шейпер) — на OUTPUT(6). Пин FB **нельзя** сажать на GND/потенциал.

**Прецедент:** Rfb/Cfb были нарисованы OUTPUT(6)↔FEEDBACK(1) — оба конца на выходном узле, на резисторе 0 В, петля ОС разомкнута, −IN без обратной связи → ОУ в насыщении, усиления ×−15 нет. Нашёл инженер на живой схеме (2026-06-XX). Исправлено: Rfb/Cfb → FB↔−IN.

**Почему пропустили (3 сетки разом):** (1) на глаз «выход→FB» выглядит как нормальная ОС; (2) ERC проверяет связность, а не смысл — висячих пинов не было; (3) `sim1_ad8000.cir` — отдельный SPICE-нетлист с правильной ОС, подтверждал номиналы, а не разводку пинов KiCad.

**Проверять:** у активных компонентов с FB-пином / внутренними соединениями — сверять пины в нетлисте с даташитом, а не полагаться на ERC. Для ОУ: Rfb обязан соединять выход с инвертирующим входом (−IN).

---

### 12. Направление тока источника в SPICE — сверять с физикой, а не копировать

**Правило:** у источника тока `Ixxx N+ N- value` ток течёт **из N+ через источник в N-**, то есть
из узла `N+` он **отбирается**. Для ФЭУ: электроны приходят на анод и уходят из вывода в схему,
условный ток течёт навстречу ⇒ **анод ЗАБИРАЕТ ток**, правильная запись `I_pmt anode 0`.
Запись `I_pmt 0 anode` вливает ток в анод — это физически неверно и разворачивает знак всего тракта.

**Прецедент (2026-08-07):** в `sim2_shaper.cir` было `I_pmt 0 anode`, а в `sim_divider_complete.cir` —
верное `I_pmt P 0`. Две деки проекта противоречили друг другу больше года. Из ошибочной выросла
документированная конвенция «импульс на АЦП идёт вниз, `amplitude = baseline − sample`», под неё были
рассчитаны делители смещения — и тракт упирался в рейлы: OPAMP1 в `VOLSAT` с ~1.2 МэВ, АЦП в `VREF+`
с ~0.70 МэВ вместо заявленных 3.5 МэВ. Исправлено сменой R313 (2к→14.7к) и R311 (5.9к→909).

**Почему пропустили:** дека сама по себе самосогласована и даёт красивые формы импульса; ошибка видна
только при сверке знака с физикой прибора либо при сравнении двух дек между собой. ERC/DRC/сборка её
не ловят в принципе.

**Проверять:** в каждой деке с источником сигнала — явно проговорить, куда течёт ток и почему.
При двух и более деках на один узел — сверять знаки между ними.

---

### 13. Правило DRC с `(min 0mm)` — это не исключение, а выключатель всей проверки

**Правило:** в `.kicad_dru` конструкция `(constraint clearance (min 0mm))` с широким условием
не «освобождает частный случай», а **перебивает остальные правила и обнуляет проверку зазора
глобально**. Проявляется молча: DRC не выдаёт ошибку разбора, он просто перестаёт что-либо находить.

**Прецедент (2026-08-08):** для 12 деталей, соединяющих ВВ-узел с землёй по схеме
(`T201, C210, D205, C410, R412, C13b201..C18b201, Q403`), было добавлено 12 правил вида
`(constraint clearance (min 0mm))` с условием `A.insideCourtyard('<ref>') && B.insideCourtyard('<ref>')`.
Результат бисекции:

```
49 ВВ-правил, без исключений   ->  59 нарушений зазора
те же 49 + 12 «исключений»     ->   0 нарушений
```

Полтора дня проект считался «чистым по электрике», хотя заливка GND стояла в **0.0005 мм**
от цепи под 908 В. Нашёл пользователь, ткнув в конкретные координаты; я до этого трижды
докладывал «нарушений нет», опираясь на молчание DRC.

**Как проверять:** подозрительное правило **убрать и перезапустить DRC**. Если число находок
выросло — правило глушило проверку. Тишина DRC не доказательство чистоты, пока не показано,
что он в принципе способен найти нарушение в этом месте (контрольный опыт: оставить одно
правило в файле и убедиться, что оно срабатывает).

**Чем заменять:** настоящие частные случаи закрывать **точечными исключениями DRC** в редакторе
(ПКМ по нарушению → «Исключить») с текстовой пометкой почему — они не влияют на остальную плату.

**Дополнительно:** консольный `kicad-cli pcb drc` **не перезаливает** зоны — он проверяет ту заливку, что
сохранена в файле. Если после правки дорожек не залить (`B`) и не сохранить, зазоры «зона↔цепь» и
`starved_thermal` будут посчитаны по устаревшей меди. Перед проверкой: заливка → сохранение → DRC.

---

### 14. Устойчивость подобрана под ПРЕДПОЛАГАЕМУЮ ёмкость — перепроверять по извлечённой с разводки

**Правило:** если устойчивость ОУ (TIA, буфер на кабель) подбиралась под оценку паразитов («Cin ≈ 10 пФ»),
после разводки извлечь реальные паразиты (FastCap/FastHenry, `simulation/tia_parasitics/`) и прогнать
устойчивость во временной области (ступенька, смотреть затухание звона), а не только малосигнальную АЧХ.
Быстрый ОУ на ёмкостную нагрузку при малом шумовом усилении — ставить R_SNUB 10–50 Ом на выход.

**Прецедент (2026-09-19):** TIA на ADA4817 рассчитан при Cin ≈ 10 пФ, решение «резистор на выходе не
ставим». FastCap по разводке дал Cin 3.4–4.6 пФ — при ней модель генерирует (~2 В); увеличение Cf
делало хуже. Лечение — R411 = 22 Ом между выводом 6 и AMP_OUT (даташит, «Driving Capacitive Loads»).
Старый свип был «устойчив» потому, что в деке стоял R418 = 33 Ом, которого нет в схеме.

**Проверять:** дека совпадает со схемой (нет лишних/отсутствующих R), паразиты — с разводки, а не с потолка.

---

## Работа с файлами нетлиста KiCad — правила верификации

### Принцип: только .net, report.txt удалён

**`.net` файл** (`gamma_spectrometer.net`) — экспортируется из текущей схемы и всегда актуален. Единственный авторитетный источник для верификации.

**report.txt удалён** (был лог аннотации — показывал значения на момент перенумерации, не текущее состояние; вводил в заблуждение).

### Как работать с .net файлом экономно (без чтения 4000+ строк)

Файл делится на два раздела:
1. `(components ...)` — определения компонентов с ref и value
2. `(nets ...)` — список цепей с узлами

**Шаг 1 — найти цепь по имени:**
```
Grep: "AMP_OUT"  →  строка с (net (code "18") (name "AMP_OUT"))
```

**Шаг 2 — прочитать только эту цепь (Read с offset):**
```
Read offset=3645 limit=10  →  видим все узлы сети AMP_OUT
```

**Шаг 3 — проверить значение компонента:**
```
Grep: "comp.*R305"  →  строка с (comp (ref "R305"))
Read offset=<строка> limit=5  →  видим (value "10k")
```

**Никогда не читать весь .net файл подряд** — это тысячи токенов впустую.
**Никогда не читать .kicad_sch файлы** — ещё больше, сжигают токены без пользы.

---

## Таблица номиналов HV board (KiCad 200-серия)

| Компонент (KiCad) | Номинал | Почему |
|---|---|---|
| R202 (FREQ) | 180кОм → 252 кГц | Эффективная работа CW на 1нФ конденсаторах |
| R201+C201 (COMP) | 1МОм + 33нФ последовательно | Медленная петля ~5 Гц; стабильность важнее быстродействия |
| C206 (bulk MAX1847) | 47мкФ X7R GRM32ER71A476KE15L | Без электролитов и тантала у ключевого преобразователя |
| R205 (CS) | 0.1Ом | Датчик тока; C205 100пФ X7R параллельно (ВЧ фильтр) |
| C208 (снаббер) | 10нФ | Демпфирование звона на Drain |
| D202+D203 (снаббер) | 2×BZT52C18 последовательно = 36В | Ограничение Vdrain; пик 38.8 В тип. / до ~45 В худш. (+VF BAS516, допуск, ТКН, L·dI/dt) → Q201 = IRLML0060 (60 В) |
| Q201 | IRLML0060 (60 В), SOT-23 | Замена IRLML0040 (40 В) 2026-09-19: «запас 4 В» не учитывал VF BAS516 и допуски — был ~1 В тип., отрицательный в худшем случае |
| C209–C216 (CW конд.) | 1нФ C0G 500В 0805, CC0805JKNPOBBN102 | Рабочее напряжение на ступень ~189В << 500В |

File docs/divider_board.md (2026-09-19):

# Делитель ФЭУ для Hamamatsu R1306/R1307

## Назначение
Активный делитель напряжения для гамма-спектрометрии с NaI(Tl) кристаллом
(типично 3"×3"), оптимизированный для скоростей счёта до 30 кимп/с.

## Содержимое проекта

- `pcb/gamma_spectrometer/gamma_spectrometer.kicad_pro` — единый KiCad проект (все 4 платы)
- `pcb/gamma_spectrometer/divider_board.kicad_sch` — схема платы делителя (в KiCad ✓, ERC ✓)
- `pcb/gamma_spectrometer.net` — нетлист (авторитетный источник, после Export Netlist)

## Электрические параметры

| Параметр | Значение |
|---|---|
| Рабочее напряжение катода | -1500 В (типично, диапазон -1000…-1500 В) |
| Полное сопротивление цепочки | 7.72 МОм |
| Ток делителя при -1500 В | 194 мкА |
| Рассеиваемая мощность | 0.29 Вт |
| Температурный коэффициент резисторов | ≤ 50 ppm/°C (TCR) |
| Точность резисторов | 1% |
| Макс. заряд анодного импульса | ~1.14 нКл (исправлено; прежние «12 нКл» завышены ×10 — `review/REVIEW.md` mn1) |
| Макс. скорость счёта | 30 кимп/с (целевая; прежние «300» — устаревший текст) |

## Распределение напряжений

✅ **Активный делитель пересобран по Hamamatsu Fig 5-15 (стр.108) и валидирован** (sim `simulation/sim_div_final.cir`, 2026-06-23). Ранние ступени — резистивные; последние (Dy6-Dy8) — транзисторные буферы Q401-403 со смещением током делителя + защитные диоды B-E. Распределение под спектрометрию (boost последних ступеней).

**Цепочка через диноды** (ток делителя ≈195 мкА смещает транзисторы ~96 мкА):

| Промежуток | Резистор | V@−1500 (sim) | Тип ступени |
|---|---|---|---|
| K - G | R401 = 750 кОм | 146 В | резистивная |
| G - Dy1 | R402 = 750 кОм | 146 В | резистивная |
| Dy1 - Dy2 | R403 = 680 кОм | 132 В | резистивная |
| Dy2 - Dy3 | R404 = 680 кОм | 132 В | резистивная |
| Dy3 - Dy4 | R405 = 680 кОм | 132 В | резистивная |
| Dy4 - Dy5 | R406 = 680 кОм | 132 В | резистивная |
| Dy5 - Dy6 | R407=1.3М (база) ‖ R408=1.3М (эмиттер) | 126 В | **буфер Q401** |
| Dy6 - Dy7 | R409 = 1.6 МОм (база) | 157 В | **буфер Q402** |
| Dy7 - Dy8 | R410 = 2.0 МОм (база) | 197 В | **буфер Q403** |
| Dy8 - GND | R412 = 2.0 МОм (база) | 198 В | — |

Все 1206 1%. Сумма = 1500 В. Ток делителя 195 мкА (sim). G — отдельный электрод между R401/R402.

**Буферы (Q401-403, MMBTA42):** эмиттер = свой динод (Dy6/Dy7/Dy8), коллектор = следующий динод / GND (Q403), база — от узла базовой нитки (R407→R409→R410→R412). Ток делителя идёт ЧЕРЕЗ диноды (R408 + эмиттер-коллектор стэка) и **смещает транзисторы ~96 мкА** (class-A). Капы C408/C409/C410 (22/47/100 нФ) — bypass последних ступеней.

**Защитные диоды B-E (D401-403, 1N4148W SOD-123):** анод→эмиттер, катод→база каждого Qхх. В норме закрыты (обратные ~0.58 В, утечка ~9 нА — смещение не трогают); при обратном B-E на рампе −HV открываются и клампят на ~0.6 В ≪ V_EBO=6 В. Защита от лавинной деградации hFE.

⚠ **Фикс C1:** Q403.C на **жёсткой GND** (не на цепочке) → средний динодный ток мимо сигнала; узел mid_P и R414 убраны.
⚠ **R1 (watch):** Vce(Q403) ≈ **198 В** (коллектор GND, эмиттер Dy8 ≈ −198 В); Vceo MMBTA42 = 300 В → запас ~100 В, ок.
⚠ **R2 (КРИТИЧНО для разводки — звёздная земля):** коллектор Q403 сажает самый большой импульсный динодный ток (пик Dy8 ~0.7 мА) на **общую GND**, куда возвращается и анодный сигнал (узел −IN TIA / AGND). Трассу коллектора Q403 вести **отдельно к точке-звезде GND**, подальше от сигнального возврата анода (REVIEW_round3 R2).
⚠ **Dy5-Dy6 = 126 В** (чуть ниже 132): transistor Vbe «съедает» пару вольт — некритично.

Сумма множителей: 11.1, базовое деление: 1500/11.1 = 135 В.

Фокусирующая сетка G подключена к узлу между R401 и R402 (mid_K).
Это создаёт соотношение K-G : G-Dy1 = 1:1 (750кОм : 750кОм),
что соответствует таблице распределения напряжений из даташита R1307 (Note 1).
G — отдельный электрод, НЕ объединяется с Dy1.

## Активные буферы

> **⚠ Эта секция переписана под фактическую активную топологию (Hamamatsu Fig 5-15, нетлист 24.06.2026).**
> Прежняя версия (база-резисторы 10к R411/R413, «динод видит ТОЛЬКО эмиттер, цепочка НЕ касается»)
> описывала ОТКЛЮЧЁННЫЙ старый делитель и **активно вредна**: по ней нельзя «чинить» плату —
> вернёте 10к/оторвёте цепочку от динода = убьёте смещение буферов (ток перестанет течь через
> транзисторы). Актуальная топология НАМЕРЕННО гонит ток делителя через диноды. См. также cheatsheet #8.

Эмиттерные повторители на NPN-транзисторах MMBTA42 (Vceo=300В, V_EBO=6В, SOT-23)
установлены на трёх последних динодах: Dy6, Dy7, Dy8. Смещены током делителя в class-A (~96 мкА).

**Две параллельные цепи** (обе стартуют с узла DY5, проверено по нетлисту):

1. **Базовая нитка** (высокоомная, задаёт опорное напряжение баз):
   `DY5 →[R407 1.3М]→ B(Q401) →[R409 1.6М]→ B(Q402) →[R410 2М]→ B(Q403) →[R412 2М]→ GND`
2. **Динодная линия** (несёт основной ток делителя — ЧЕРЕЗ диноды и переходы C→E транзисторов):
   `DY5 →[R408 1.3М]→ DY6 = E(Q401);  C(Q401)→DY7 = E(Q402);  C(Q402)→DY8 = E(Q403);  C(Q403)→GND`

| Динод | Транзистор | Эмиттер | Коллектор | База ← резистор | Накопит. C |
|---|---|---|---|---|---|
| Dy6 | Q401 | DY6 (J_PMT401.8) | DY7 | узел Net-(D401-K) ← R407 (1.3М, от DY5) | C408 = 22 нФ / 1 кВ (DY6–DY7) |
| Dy7 | Q402 | DY7 (J_PMT401.9) | DY8 | узел Net-(D402-K) ← R409 (1.6М) | C409 = 47 нФ / 1 кВ (DY7–DY8) |
| Dy8 | Q403 | DY8 (J_PMT401.10) | **GND** (фикс C1) | узел Net-(D403-K) ← R410 (2.0М) | C410 = 100 нФ / 1 кВ (DY8–…) |

**Принцип:** ток делителя втекает с GND через коллектор Q403 → его эмиттер (Dy8) → коллектор Q402
→ эмиттер (Dy7) → коллектор Q401 → эмиттер (Dy6) → R408 → DY5 → основная резистивная цепочка.
Тем самым каждый транзистор смещён в активный режим (Vbe≈+0.57 В, Ic≈96 мкА) — и при импульсе
динода отдаёт пиковый ток с коллектора, не просаживая опорное напряжение. Накопительные капы
C408-C410 (между соседними эмиттерными/динодными линиями) дают мгновенный заряд на фронте.

**⚠ Топология (критично):**
- **Эмиттер** Qхх → свой динод ФЭУ; **коллектор** → следующий (менее отрицательный) динод; у Q403 — **GND** (фикс C1).
- **База** Qхх → узел базовой нитки (Net-(Dxxx-K)), куда сходятся два базовых резистора + катод защитного диода.
- **R408 (эмиттерный, 1.3М)** соединяет DY5↔DY6 — ток делителя НАМЕРЕННО проходит через динодную линию (это и даёт 96 мкА смещения). Это НЕ ошибка «цепочка коснулась динода» — в активном делителе так и должно быть.
- Защитные диоды D401-403: анод→эмиттер(динод), катод→база (защита перехода B-E, V_EBO=6В — см. ниже).
- ⚠ **Анти-паттерн (старая ошибка):** нельзя вести базовый резистор на узел, который и есть собственный эмиттер транзистора — тогда V_BE=0, буфер заперт. Базовая нитка и динодная линия должны оставаться РАЗДЕЛЬНЫМИ цепями (соприкасаются только через переход B-E транзистора).

Контрольные узлы (по нетлисту 24.06):
```
DY5  : R406.2 + R407.1 + R408.1 + J_PMT401.7
DY6  : Q401.E + R408.2 + C408.1 + D401.A + J_PMT401.8
DY7  : Q402.E + Q401.C + C408.2 + C409.1 + D402.A + J_PMT401.9
DY8  : Q403.E + Q402.C + C409.2 + C410.1 + D403.A + J_PMT401.10
base1: Q401.B + R407.2 + R409.1 + D401.K     (Net-(D401-K))
base2: Q402.B + R409.2 + R410.1 + D402.K     (Net-(D402-K))
base3: Q403.B + R410.2 + R412.1 + D403.K     (Net-(D403-K))
Q403.C → GND ;  R412.2 → GND
```

Просадка напряжения на накопительных конденсаторах (расчёт для старого 12 нКл; реальный заряд ~1.14 нКл ⇒ просадка ещё ~×10 меньше):
- C408 (22 нФ): 0.55 мВ → 0.4% от 136 В (Dy6 уровень)
- C409 (47 нФ): 0.26 мВ → 0.16%
- C410 (100 нФ): 0.12 мВ → 0.06%

## Анодная цепь и предусилитель — TIA на ADA4817-1ARDZ

✅ **Реализовано (2026-06-24):** вход — **трансимпедансный усилитель (TIA) на ADA4817-1ARDZ (U402)**, заменил AD8000-инвертор. Дешевле ~вдвое, **−18% шума** (76.9 vs 94.4 мкВ), идеальная линейность (анод на виртуальной земле). Подтверждено единой моделью `simulation/sim_divider_complete.cir` + `sim_tia_real.cir` (офиц. модель ADI). FET-вход (i_n=2.5фА), noise gain ≈1.

Анод (P, pin 11) — **напрямую на −IN** (виртуальная земля ≈ 0 В). **Rin/Rg убраны** (R415/R416 удалены): весь ток анода втекает в −IN и уходит через Rf. C11 не нужен (DC анода ≈ 0).

### TIA (ADA4817-1, U402) — gain = Zt = Rf
```
анод P (J_PMT401.11) ──┬── −IN (pin 2)        (виртуальная земля ≈ 0 В)
   FB(1) ─ Rf 499 ─────┤
   FB(1) ─ Cf 4.7п ────┘
              +IN (pin 3) = AGND    (виа в паде → GND-заливка B.Cu, 2026-09-19)
              PD  (pin 8) = +5V_A   (вкл: PD в пределах 0.9В от +VS)
              −VS (pin 4) = −5V_A ;  +VS (pin 7) = +5V_A
              NIC (pin 5) = не подключать ;  EPAD = AGND
              OUT (pin 6) ── R411 22 Ом (R_SNUB) ── AMP_OUT → коаксиал → MCU
                             (вплотную к pin 6; обратная связь Rf/Cf — с pin 1, ДО резистора)
```
- ⚠ **R411 = 22 Ом (R_SNUB) на выходе ОБЯЗАТЕЛЕН (2026-09-19).** Извлечение паразитов с разводки
  (`simulation/tia_parasitics/`, FastCap) дало Cin = **3.4–4.6 пФ**, а не ~10 пФ, под которые подбиралась
  устойчивость. При такой Cin без резистора модель ADA4817 **генерирует** (~2 В размаха) на ёмкостную
  нагрузку «кабель + вход шейпера» и даже на одни 3 пФ; с 22 Ом устойчиво при Cin 3–10 пФ и петле ОС
  1–10.7 нГн (выброс ~0.1 %). Совпадает с даташитом ADA4817 «Driving Capacitive Loads» (R_SNUB 10–50 Ом).
  Увеличение Cf **не** лечит (хуже). Влияние на усиление ~0.2 % (нагрузка R309 = 10 кОм) — в калибровку.
- **Трансимпеданс Zt = Rf = 499 Ом.** V_out = −I_anode × 499. Cs-137 (0.94 мА) → 469 мВ; **3.5 МэВ (4.97 мА) → 2.47 В** (sim, без клиппинга, ~80% АЦП — запас есть; Rf=470 дал бы 2.34 В как у AD8000).
- **Cf = 4.7 пФ** — устойчивость TIA при Cin≈10 пФ: пик **+0.00 дБ**, полоса 98 МГц
  (`sim_tia_cin_sweep.cir`, поточечный замер |Zt(f)|, 2026-08-07). Номинал подобран верно:
  полоса немонотонна по Cin (89.5 МГц при 5 пФ → максимум 97.9 при 10 пФ → дальше вниз),
  то есть оптимум компенсации приходится ровно на ожидаемую ёмкость узла.
- ⚠ **FB(1) внутри = OUT(6)** (ADA4817 «Low Distortion Pinout») → Rf/Cf обязательно между **FB и −IN**, НЕ на OUT (cheatsheet #11).
- ✅ **Питание ADA4817 проверено расчётом (2026-09-19):** рабочий диапазон 5–10 В, абс. макс 10.6 В.
  ±5V_A не стабилизированы (сырой USB через LC; −5 В — инвертор TPS60400). При питании от ПК
  (USB 4.75–5.25 В): +5V_A 4.61–5.11 В, −5V_A −3.63…−4.13 В, **размах 8.2–9.2 В** — в норме.
  Держится на том, что летающий C111 = 0.1 мкФ (не 1 мкФ по даташиту TPS60400): Ro инвертора ~50 Ом,
  −5 В проседает на токе покоя ОУ 19 мА. **C111 на 1 мкФ без стабилизатора не менять** (размах → ~10 В
  при 5.25 В). От «левой» зарядки 5.5 В: ADA4817 9.7 В — ок, но вход TPS60400 5.36 В > рабочих 5.25 В.
  Прибор по умолчанию питается от ПК — LDO не ставим.
- Развязки ±5V_A: C411-C414 (4.7мкФ X5R ‖ 100нФ X7R) у пинов питания (феррит-бусины не нужны — ±5V_A уже LC-фильтрованы на USB board).

**Компоненты входа (TIA):**
| Ref (KiCad) | Компонент | Номинал | Корпус |
|---|---|---|---|
| U402 | ADA4817-1ARDZ | VFB FET TIA, ±5В | SOIC-8 (RD-8-4, EPAD) |
| R417 (Rf) | **499 Ом 1%** | трансимпеданс | 0402 |
| R411 (R_SNUB) | **22 Ом 1%** (RC0402FR-0722RL) | развязка выхода от ёмкостной нагрузки | 0402 |
| C415 (Cf) | **4.7 пФ NP0** | устойчивость TIA | 0402 |
| C411 | 4.7 мкФ X5R | −5V_A развязка | 0805 |
| C412 | 100 нФ X7R | −5V_A развязка | 0402 |
| C413 | 4.7 мкФ X5R | +5V_A развязка | 0805 |
| C414 | 100 нФ X7R | +5V_A развязка | 0402 |
| J_sig | U.FL разъём | сигнальный выход | SMD |

---

> _История: вход переведён с AD8000-инвертора на ADA4817 TIA (решение 2026-06-21, реализовано 2026-06-24). Полное описание — раздел «Анодная цепь и предусилитель — TIA» выше._

**Ключевые требования к разводке TIA:**
- Узел −IN (= анод P) — минимальной площади/ёмкости: трасса анод→−IN и Rf/Cf к −IN короткие, без via. **Cin держать ≤ 20 пФ** (при 20 пФ подъём +0.58 дБ — в пределах обычного допуска; при 30 пФ +1.6 дБ; «плохо» начинается с 40–50 пФ). Прежнее «≤10 пФ, край пропасти» опиралось на сломанную метрику — см. поправку в `review/REVIEW_divider_latest.md`.
- Cf=4.7 пФ между FB и −IN — обязателен (устойчивость TIA).
- Развязки ±5V_A: ≤ 5 мм от пинов V+/V−
- AGND: отдельный полигон в зоне TIA (U402), одна точка соединения с GND делителя

## Развязочные / накопительные конденсаторы

> **⚠ Переписано 2026-06-24 под нетлист.** Прежняя версия описывала bypass C401-C407 на ранних
> ступенях — их в схеме НЕТ (нетлист содержит только C408/C409/C410). Ставить bypass на каждый
> резистор цепочки в активном делителе не требуется.

В схеме присутствуют **только три конденсатора** последних (буферных) ступеней — они одновременно
накопительные (отдают пиковый ток на фронте импульса) и развязочные:

| Конд. | Между | Номинал |
|---|---|---|
| C408 | DY6 – DY7 | 22 нФ / 1 кВ |
| C409 | DY7 – DY8 | 47 нФ / 1 кВ |
| C410 | DY8 – … | 100 нФ / 1 кВ |

Ранние резистивные ступени (R401-R406) отдельными bypass-конденсаторами **не шунтируются**:
ток на ранних динодах мал (вклад вторички ничтожен), просадка опорного напряжения несущественна.
Пиковый ток испытывают только последние диноды Dy6-Dy8 — их и держат буферы + C408-C410.

## Подключение к остальным платам стека

### 1. −ВВ от платы ВВ питания
**TP1** (-HV): экранированный провод ≥ 5 кВ изоляция (ПВВ-1 или аналог).
Приходит от платы ВВ, минуя плату МК (вдоль края стека).
Минимальный зазор от других цепей: 5 мм.

### 2. GND
**TP2**: провод возврата, соединяется с GND стека на плате МК.

### 3. Питание TIA ADA4817 (от платы МК)
**J_pwr** — 3-пиновый JST PH 2.0 мм:

| Пин | Сигнал | От платы МК |
|---|---|---|
| 1 | +5V_A | pin 1 header MCU→divider |
| 2 | AGND | GND |
| 3 | −5V_A | pin 2 header MCU→divider |

Кабель: витая пара (±5V_A) + GND, длина ≤ 50 мм.

### 4. Сигнал TIA (на плату МК)
**J_sig** — U.FL разъём. Выход TIA ADA4817 (**+469 мВ** для Cs-137, Zt=499 Ω; верифицировано sim).
Знак положительный: анод забирает ток из виртуальной земли ⇒ выход TIA идёт вверх (2026-08-07).
Кабель: RG-178 (50 Ом), длина ≤ 100 мм, на плате МК → U.FL вход шейпера.

*Коаксиал несёт УСИЛЕННЫЙ сигнал ~470 мВ (Cs-137) вместо прежних 31 мВ —
на порядок меньше чувствителен к наводкам.*

**Почему именно коаксиал, а не одиночный провод** (разобрано 2026-08-07): решает не длина линии,
а наводка. Круговая задержка 100 мм ≈ 1 нс против фронта TIA ~4 нс — отражения тонут внутри
фронта, по этому пункту оба варианта равны. Но шумовой бюджет фронт-энда **σ = 76.9 мкВ**, а
кабель идёт в 6–12 мм от флайбэка MAX1847 (252 кГц) и вдоль провода −ВВ. Одиночный провод даёт
петлю в квадратные сантиметры и ловит милливольты **когерентной** помехи 252 кГц — она поедет
baseline, а не просто добавит σ. У коаксиала обратный ток течёт по оплётке вплотную к жиле,
петли нет. Оплётку паять на GND **с обоих концов** (фронты наносекундные, оплётка = обратный
проводник), хвостик оплётки — минимальной длины.

**Последовательный резистор на выходе TIA — решено НЕ ставить** (2026-08-07). Проверено
`sim_tia_cable_ac.cir` / `sim_tia_cable_tran.cir` (модель кабеля: линия Z0=50, Td=0.48 нс +
реальный вход шейпера): выход ADA4817 гонит коаксиал напрямую, и это **безопасно** — пиковость
|Zt| +0.00 дБ при любом Rs от 0 до 100 Ом, пик на импульсе 3.5 МэВ не меняется (2.4705 В),
обратный выброс 4.2 мВ. Исходная гипотеза «ОУ зазвенит на ёмкость кабеля» **не подтвердилась**:
отрезок линии на ВЧ выглядит как 50 Ом активных, а не как конденсатор.
⚠ Остаточный эффект, принятый осознанно: разомкнутая на дальнем конце линия имеет резонанс
~300–500 МГц (на 300 МГц |Zt| возвращается к 471 Ом против 60 Ом с резистором 47 Ом). Сигналу
это безразлично — там его нет; это лишь незакрытый путь для ВЧ-наводки на кабель. Резистор
33–47 Ом закрыл бы его ценой 0.3–0.5 % амплитуды, но плата разведена без него.

## Pt1000 термодатчик

Pt1000 (Honeywell 700-102BAA-B00, 1 кΩ @ 0°C, M222 leaded) **не размещается** на
плате делителя. Вместо этого он крепится снаружи на корпус кристалла
(тонкая медная скобка или термоклей) и подключается к плате АЦП витой
парой. Это даёт лучшую корреляцию с температурой кристалла, который
является основным источником температурного дрейфа (-0.3%/°C световыхода
для NaI(Tl)).

## Подключение выводов R1307-01

R1307-01 — модификация с гибкими выводами (без цоколя). По **обмеру** (2026-06-16):
18 угловых слотов по 20°, диаметр окружности выводов **Ø35 мм** (по центрам), вывод Ø0.7,
расстояние между соседними выводами ~5 мм. Из 18 слотов реально присутствуют **11 выводов**
(7 отсутствуют). Маска присутствия от анода по часовой: `100011110011111100`.

В KiCad представлен как **J_PMT401 = Conn_01x11** с логической нумерацией 1–11. Реальная
распиновка по часовой от анода: **P, _, _, _, G, K, Dy1, Dy2, _, _, Dy3, Dy4, Dy5, Dy6, Dy7, Dy8, _, _**
(сетка G идёт раньше катода K — это не опечатка):

| Пин J_pmt | Электрод | Слот (из 18) | Угол CW от анода | Подключение |
|---|---|---|---|---|
| 1 | K (катод) | 6 | 100° | −HV вход (TP1) |
| 2 | G (фокусирующий электрод) | 5 | 80° | Узел R401–R402 (mid_K, −HV+145В) |
| 3 | Dy1 | 7 | 120° | Узел R402–R403 (−HV+290В) |
| 4 | Dy2 | 8 | 140° | Узел между R403–R404 |
| 5 | Dy3 | 11 | 200° | Узел между R404–R405 |
| 6 | Dy4 | 12 | 220° | Узел между R405–R406 |
| 7 | Dy5 | 13 | 240° | Узел между R406–R407 |
| 8 | Dy6 | 14 | 260° | Метка DY6 (эмиттер Q401) |
| 9 | Dy7 | 15 | 280° | Метка DY7 (эмиттер Q402) |
| 10 | Dy8 | 16 | 300° | Метка DY8 (эмиттер Q403) |
| 11 | P (анод) | 1 | 0° | напрямую на −IN (pin 2) ADA4817 (виртуальная земля); Rin/Rg убраны |

**Footprint:** `J_PMT401_R1307-01` в библиотеке `посадочные места` (сделан 2026-06-16).
Окружность выводов уменьшена до **Ø30 (R15)** — на 2.5 мм от номинала Ø35 (гибкие выводы
длиной 25 мм нормально подгибаются), чтобы освободить кольцо под крепёжные стойки M2.5.
Отверстие Ø1.0 под вывод Ø0.7, пэд Ø1.8. Ориентация — **вид со стороны контактов / с торца USB,
НЕ зеркалить** (см. правило ориентации плат). Пэд «1»(K) помечен квадратом, «P» подписан.

## Рекомендации по разводке PCB

1. Плата круглая, диаметр **~42-45 мм** (увеличено с 35-40 мм для размещения TIA ADA4817).
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

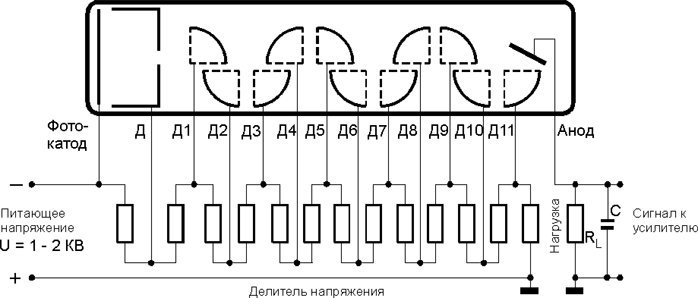
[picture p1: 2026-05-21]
docs/refs/ris6-1.gif

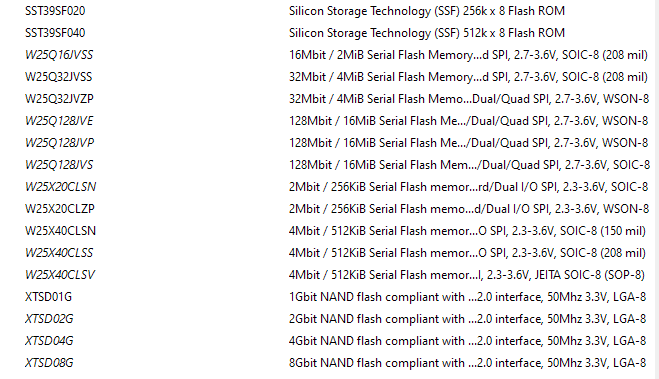
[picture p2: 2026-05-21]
pcb/Screenshots/Снимок экрана 2026-05-20 224756.png

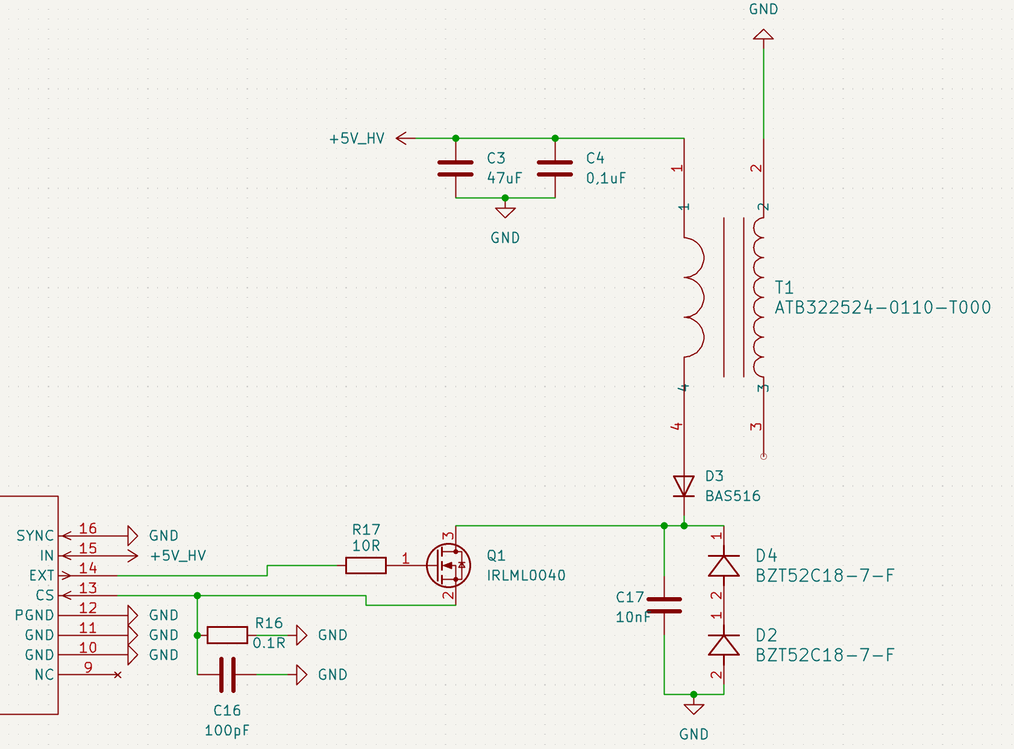
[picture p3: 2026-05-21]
pcb/Screenshots/Снимок экрана 2026-05-17 005503.png

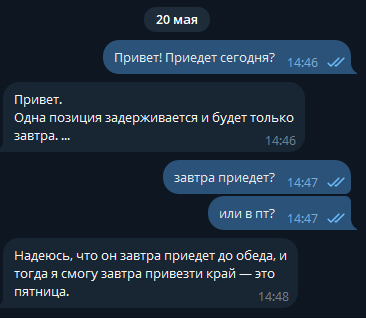
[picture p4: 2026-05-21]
pcb/Screenshots/Снимок экрана 2026-05-20 150148.png

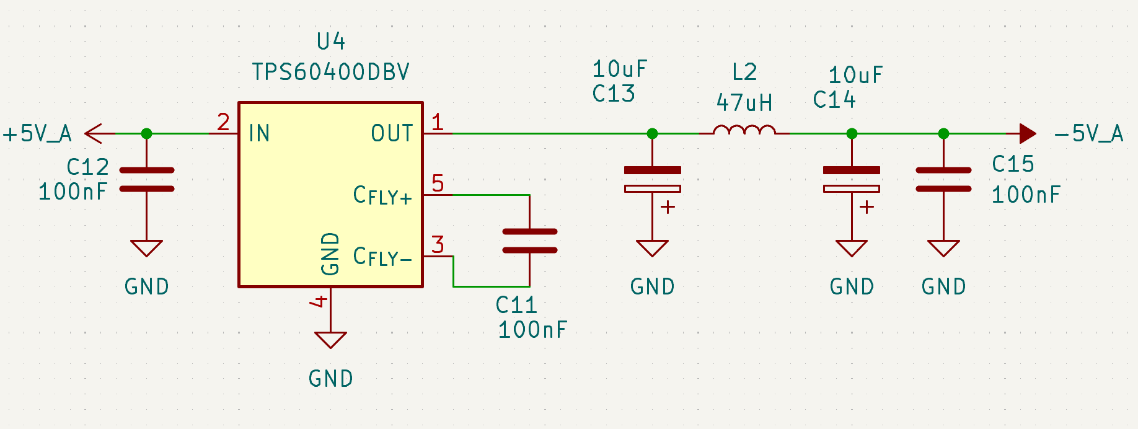
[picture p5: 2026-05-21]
pcb/Screenshots/Снимок экрана 2026-05-16 021712.png

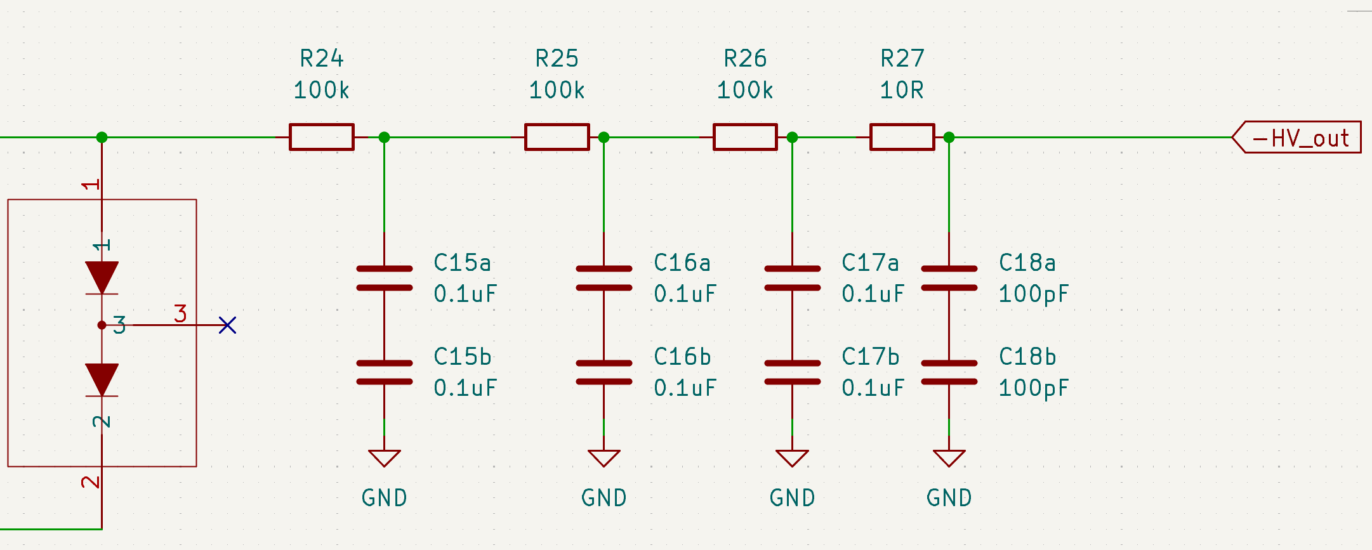
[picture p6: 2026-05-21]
pcb/Screenshots/Снимок экрана 2026-05-17 024256.png

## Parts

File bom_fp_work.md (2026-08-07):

# BOM — финальное состояние

> **Статус:** ВСЕ КОМПОНЕНТЫ НАЗНАЧЕНЫ ✅ (включая J_PMT401 — футпринт `J_PMT401_R1307-01` сделан, Ø30)
> Свежий нетлист: `pcb/gamma_spectrometer.net` (2026-06-24, 177 компонентов: 74 конд. + 63 рез. + активные/прочие)
> ⚠ **Правки 2026-08-07 ещё НЕ в нетлисте** (схему правит пользователь): R313 2к→14.7к, R311 5.9к→909,
> U301 TL431→REF35250 (SOT-23-6), R301 удалён, C303 100нФ→1мкФ, добавлен C322 1мкФ.
> После правки схемы: 75 конденсаторов, 62 резистора, всего 177.
> Свежий BOM: см. ниже / экспорт из KiCad

---

## Сводный BOM (финальный)

### Конденсаторы — 17 уникальных MPN, 74 шт

| Refs | Qty | Value | MPN | Footprint |
|---|---|---|---|---|
| C13a201, C13b201, C14a201, C14b201, C15a201, C15b201, C16a201, C16b201, C17a201, C17b201, C410 | 11 | 0.1uF / 1кВ | C1812X104K102T (Holy Stone) | C_1812_HandSolder |
| C18a201, C18b201 | 2 | 220pF / 1кВ C0G | CC1206JKNPOCBN221 (Yageo) | C_1206_HandSolder |
| C101, C104, C105, C112, C113 | 5 | 10uF тант. | TR3B106K010C0750 (Vishay) | CP_EIA-3528-21_Kemet-B_HandSolder |
| C102, C107-C111, C114, C116, C203, C204, C207, C217, C304-C309, C311-C314, C317, C319-C321, C412, C414 | 28 | 0.1uF X7R | CC0603JRX7R9BB104 (Yageo) | C_0603_HandSolder |
| C103, **C303**, **C322** | 3 | 1uF X7R | CC0805JKX7R9BB105 (Yageo) | C_0805_HandSolder — C303 выход REF35250 (обязателен 0.1…10 мкФ), C322 на вывод NR |
| C106, C310, C411, C413 | 4 | 4.7uF X5R | GRM21BR61C475KA88L (Murata) | C_0805_HandSolder |
| C115, C206 | 2 | 47uF X7R | GRM32ER71A476KE15L (Murata) | C_1210_HandSolder |
| C201 | 1 | 33nF X7R | CC0805JRX7R9BB333 (Yageo) | C_0805_HandSolder |
| C202 | 1 | 0.47uF X7R | CC0805JKX7R9BB474 (Yageo) | C_0805_HandSolder |
| C205, C315, C318 | 3 | 100pF C0G | CC0603JRNPO9BN101 (Yageo) | C_0603_HandSolder |
| C208 | 1 | 10nF X7R | CC0603KRX7R9BB103 (Yageo) | C_0603_HandSolder |
| C209-C216 | 8 | 1nF / 500В C0G | CC0805JKNPOBBN102 (Yageo) | C_0805_HandSolder |
| C301, C302 | 2 | 18pF C0G | CC0402FRNPO9BN180 (Yageo) | C_0402_HandSolder |
| C316 | 1 | 510pF C0G | CC0603FRNPO9BN511 (Yageo) | C_0603_HandSolder |
| C408 | 1 | 22nF / 1кВ | CC1210KKX7RCBB223 (Yageo) | C_1210_HandSolder |
| C409 | 1 | 47nF / 1кВ | GRM43DR73A473KW01L (Murata) | C_1812_HandSolder |
| C415 (Cf, TIA) | 1 | 4.7pF C0G NP0 | GRM1555C1H4R7CA01D (Murata) | C_0402_HandSolder |

### Резисторы — стандартные 0603 (1%, низковольтные)

| Refs | Qty | Value | MPN | Серия |
|---|---|---|---|---|
| R101, R102 | 2 | 330R | RT0603BRD07330RL | Yageo RT (thin film) |
| R201 | 1 | 1M | RT0603BRD071ML | Yageo RT (thin film) |
| R202 | 1 | 180k | RC0603FR-07180KL | Yageo RC |
| R203, R220, R231, R232 | 4 | 100k | RC0603FR-07100KL | Yageo RC |
| R204, R302-R305, R307, R309, R408, R411, R413 | 10 | 10k | RC0603FR-0710KL | Yageo RC (R303 = Pt1000 pull-up) |
| R205 | 1 | 0.1R | RL0603FR-070R1L | Yageo RL (current sense) |
| R206, R233 | 2 | 10R | AC0603FR-0710RL | Yageo AC (anti-surge) |
| R208 | 1 | 2.2M | RC0603FR-072M2L | Yageo RC |
| R218 | 1 | 1.2k | RC0603FR-071K2L | Yageo RC |
| R219 | 1 | 110k | RC0603FR-07110KL | Yageo RC |
| ~~R301~~ | — | ~~330R~~ | — | **УДАЛЁН 2026-08-07**: балласт шунта TL431 не нужен последовательной опоре REF35250 |
| R306, R308 | 2 | 1k | RC0603FR-071KL | Yageo RC |
| R310 | 1 | 22k | RC0603FR-0722KL | Yageo RC |
| R311 | 1 | **909R** | RC0603FR-07909RL | Yageo RC (было 5.9k; смена полярности 2026-08-07) |
| R312 | 1 | 8.2k | RC0603FR-078K2L | Yageo RC |
| R313 | 1 | **14.7k** | RC0603FR-0714K7L | Yageo RC (было 2k; смена полярности 2026-08-07) |
| R417 (Rf, TIA) | 1 | 499R | RC0603FR-07499RL | Yageo RC (вход TIA; Rin/Rg R415/R416 убраны) |
| R_CC101, R_CC102 | 2 | 5.1k | RC0603FR-075K1L | Yageo RC |

**Все 0603 footprint:** Resistor_SMD:R_0603_1608Metric_Pad0.98x0.95mm_HandSolder

### Резисторы — высоковольтные 1206

| Refs | Qty | Value | MPN | Серия |
|---|---|---|---|---|
| R207, R209-R217 | 10 | 100M | RC1206JR-07100ML (5%) | Yageo RC |
| R221-R230 | 10 | 6.8M | RC1206FR-076M8L (1%) | Yageo RC |
| R401, R402 | 2 | 750k | RC1206FR-07750KL | Yageo RC |
| R403-R406 | 4 | 680k | RC1206FR-07680KL | Yageo RC |
| R407, R408 | 2 | 1.3M | RC1206FR-071M3L | Yageo RC (база+эмиттер буфера Q401, пересборка по Fig 5-15) |
| R409 | 1 | 1.6M | RC1206FR-071M6L | Yageo RC |
| R410 | 1 | 2M | RC1206FR-072ML | Yageo RC |
| R412 | 1 | 2M | RC1206FR-072ML | Yageo RC (фикс C1: R414/mid_P убраны) |

**Все 1206 footprint:** Resistor_SMD:R_1206_3216Metric_Pad1.30x1.75mm_HandSolder

### Активные / разное

| Refs | Qty | Value | MPN | Footprint |
|---|---|---|---|---|
| D101 | 1 | LED синий | FYLS-0805UBC (Foryard) | LED_0805_HandSolder |
| D102 | 1 | LED зелёный | 150080GS75000 (Würth) | LED_0805_HandSolder |
| D201 | 1 | BAS516 | BAS516 (YJ) | D_SOD-523 |
| D202, D203 | 2 | BZT52C18 | BZT52C18 (Diotec) | Nexperia_CFP3_SOD-123W ⚠ проверить |
| D204-D211 | 8 | BAV23S | BAV23S (Nexperia) | SOT-23 |
| D401-D403 | 3 | 1N4148W | 1N4148W (onsemi/Diotec) | Diode_SMD:D_SOD-123 (защита B-E буферов Q401-403) |
| F101 | 1 | PTC 500мА | MF-MSMF050-2 (JEMETE) | Fuse_1812_HandSolder |
| FB301 | 1 | 120Ω@100МГц | BLM18EG121SN1D (Murata) | L_0603_HandSolder |
| J101 | 1 | USB-C | DX07S024WJ3R400 (JAE) | USB_C_Receptacle_JAE |
| J_PMT401 | 1 | ФЭУ R1307-01 | — | **J_PMT401_R1307-01** (своя библ. «посадочные места», Ø30, 18 слотов, готов) |
| L101, L102 | 2 | 47uH | SRN3015-470M (Bourns) | L_Neosid_SMS-ME3015 |
| L103 | 1 | 100uH | SRU5028-101Y (Bourns) | L_Bourns_SRU5016_5.2x5.2mm |
| Q201 | 1 | IRLML0040 | IRLML0040 (HOTTECH) | SOT-23 |
| Q401-Q403 | 3 | MMBTA42 | MMBTA42 (Diotec) | SOT-23 |
| T201 | 1 | 1:10.2 трансф. | ATB322524-0110-T000 (TDK) | CHOKE_524-0110-T000_TDK-M |
| U101 | 1 | LP5907MFX-3.3 | LP5907MFX-3.3 (TECH PUB) | SOT-23-5 |
| U102 | 1 | AMS1117-3.3 | AMS1117-3.3 (YOUTAI) | SOT-223-3 |
| U103 | 1 | FT231XQ | FT231XQ | QFN-20-1EP_4x4mm |
| U104 | 1 | TPS60400DBV | TPS60400DBV (TI) | SOT-23-5 |
| U201 | 1 | MAX1847EEE+ | MAX1847EEE+ (AliExpress) | QSOP-16 (21-0055H_16_MXM-M) |
| U202 | 1 | TL431 | TL431 (YOUTAI) | SOT-23 |
| **U301** | 1 | **REF35250** | **REF35250QDBVR** (TI) | **SOT-23-6 (DBV)** — опора 2.5 В, 12 ppm/°C |
| U302 | 1 | STM32G474MET6 | STM32G474MET6 (ST) | LQFP-80 |
| U303 | 1 | W25Q64JVSSIQ | W25Q64JVSSIQ (Winbond) | SOIC-8 |
| U402 | 1 | ADA4817-1ARDZ | ADA4817-1ARDZ (ADI) | SOIC-8 RD-8-4 (RD_8_1_ADI-M) — TIA вход |
| U_ESD101 | 1 | PRTR5V0U2X | PRTR5V0U2X (YOUTAI) | SOT-143 |
| Y301 | 1 | кварц 16МГц | ABM8G-16.000MHZ-4Y-T3 (Abracon) | Crystal_SMD_3225-4Pin |
| (внешн.) | 1 | Pt1000 термодатчик | 700-102BAA-B00 (Honeywell, артикул 32208572) | M222 leaded, не на PCB — крепится на корпус кристалла, витой парой к TSENS_PWR/TSENS_IN |

---

## ⚠ К проверке перед заказом

1. **🔴 D202, D203 footprint SOD-123W — ОБЯЗАТЕЛЬНО ИСПРАВИТЬ** — BZT52C18 от Diotec в стандартном SOD-123 (2.6×1.5мм). SOD-123W (3.7×1.6мм) шире на 0.8мм. Диоды не пропаяются на широком footprint. Поменять на `Diode_SMD:D_SOD-123`.

2. **U301 заменён на REF35250QDBVR** (2026-08-07, по ревью): параметрический шунт TL431 → последовательная опора,
   12 ppm/°C вместо 50 (у клона YOUTAI до 300). Дрейф калибровки на ±30 °C: 0.9 % → **0.036 %**. Критично потому,
   что эта опора задаёт и шкалу АЦП (`VREF+`), и рабочие точки шейпера (делители A/B).
   **U202 на ВВ-плате остаётся TL431** — он питает только делитель мониторинга ВВ, в энергошкале не участвует.

3. ~~R412, R414 URL~~ — ✅ исправлено.

4. ~~J_PMT401~~ — ✅ сделан `J_PMT401_R1307-01` в библиотеке «посадочные места» (по реальному обмеру: 11 pad, окружность выводов Ø35→**Ø30** под стойки, 18 слотов × 20°, отверстие Ø1.0 под вывод Ø0.7). Проверить линейкой в редакторе перед заказом.

---

## Дальнейшие этапы

1. **Заказ компонентов** — закрыть все ⚠ выше, оформить заказ
2. **Разводка PCB** (по порядку):
   1. USB/Power board — простейшая
   2. Divider board — Ø42-45мм, footprint ФЭУ `J_PMT401_R1307-01` готов (Ø30)
   3. HV board — ВВ зазоры, силиконовая заливка
   4. MCU board — аналоговый тракт, 4 слоя
3. **STM32 прошивка** — DMA ADC, пик-детектор, гистограмма 8192, shproto
4. **Host software** — BecqMoni совместимость

---

## Финальная статистика

- **Уникальных MPN:** 60+
- **Конденсаторов:** 74 → **75** после добавления C322 (17 MPN)
- **Резисторов:** 63 → **62** после удаления R301 (28 MPN: 21 серии 0603 + 7 серий 1206)
- **Активных:** 27 (включая 8 BAV23S, 8 BZT52, 3 MMBTA42, 3×1N4148W защита B-E; вход — ADA4817-1ARDZ TIA вместо AD8000)
- **Магнитных:** 4 (T201 + L101/102/103)
- **Прочих пассивов:** 6 (F101, FB301, D101, D102, D201, J101)
- **Разъёмов:** 2 (J101 USB-C, J_PMT401 кастомный)

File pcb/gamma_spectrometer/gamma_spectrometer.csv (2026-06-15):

Reference | Qty | Value | PN | Footprint | Ссылка на покупку
C13a201,C13b201,C14a201,C14b201,C15a201,C15b201,C16a201,C16b201,C17a201,C17b201,C401,C402,C403,C404,C405,C406,C407,C410 | 18 | 0.1uF | C1812X104K102T | Capacitor_SMD:C_1812_4532Metric_Pad1.57x3.40mm_HandSolder | https://www.electronshik.ru/item/HOLY/C1812X104K102T
C18a201,C18b201 | 2 | 220pF | CC1206JKNPOCBN221 | Capacitor_SMD:C_1206_3216Metric_Pad1.33x1.80mm_HandSolder | https://www.electronshik.ru/item/YAG/CC1206JKNPOCBN221
C101,C104,C105,C112,C113 | 5 | 10uF | TR3B106K010C0750 | Capacitor_Tantalum_SMD:CP_EIA-3528-21_Kemet-B_HandSolder | https://www.electronshik.ru/item/VISHAY/TR3B106K010C0750
C102,C107,C108,C109,C110,C111,C114,C116,C203,C204,C207,C217,C303,C304,C305,C306,C307,C308,C309,C311,C312,C313,C314,C317,C319,C320,C321,C412,C414 | 29 | 0.1uF | CC0603JRX7R9BB104 | Capacitor_SMD:C_0603_1608Metric_Pad1.08x0.95mm_HandSolder | https://www.electronshik.ru/item/YAG/CC0603JRX7R9BB104
C103 | 1 | 1uF | CC0805JKX7R9BB105 | Capacitor_SMD:C_0805_2012Metric_Pad1.18x1.45mm_HandSolder | https://www.electronshik.ru/item/YAG/CC0805JKX7R9BB105
C106,C310,C411,C413 | 4 | 4.7uF | GRM21BR61C475KA88L | Capacitor_SMD:C_0805_2012Metric_Pad1.18x1.45mm_HandSolder | https://www.electronshik.ru/item/MUR/GRM21BR61C475KA88L
C115,C206 | 2 | 47uF | GRM32ER71A476KE15L | Capacitor_SMD:C_1210_3225Metric_Pad1.33x2.70mm_HandSolder | https://www.electronshik.ru/item/MUR/GRM32ER71A476KE15L
C201 | 1 | 33nF | CC0805JRX7R9BB333 | Capacitor_SMD:C_0805_2012Metric_Pad1.18x1.45mm_HandSolder | https://www.electronshik.ru/item/YAG/CC0805JRX7R9BB333
C202 | 1 | 0.47uF | CC0805JKX7R9BB474 | Capacitor_SMD:C_0805_2012Metric_Pad1.18x1.45mm_HandSolder | https://www.electronshik.ru/item/YAG/CC0805JKX7R9BB474
C205,C315,C318 | 3 | 100pF | CC0603JRNPO9BN101 | Capacitor_SMD:C_0603_1608Metric_Pad1.08x0.95mm_HandSolder | https://www.electronshik.ru/item/YAG/CC0603JRNPO9BN101
C208 | 1 | 10nF | CC0603KRX7R9BB103 | Capacitor_SMD:C_0603_1608Metric_Pad1.08x0.95mm_HandSolder | https://www.electronshik.ru/item/YAG/CC0603KRX7R9BB103
C209,C210,C211,C212,C213,C214,C215,C216 | 8 | 1nF | CC0805JKNPOBBN102 | Capacitor_SMD:C_0805_2012Metric_Pad1.18x1.45mm_HandSolder | https://www.electronshik.ru/item/YAG/CC0805JKNPOBBN102
C301,C302 | 2 | 18pF | CC0402FRNPO9BN180 | Capacitor_SMD:C_0402_1005Metric_Pad0.74x0.62mm_HandSolder | https://www.electronshik.ru/item/YAG/CC0402FRNPO9BN180
C316 | 1 | 510pF | CC0603FRNPO9BN511 | Capacitor_SMD:C_0603_1608Metric_Pad1.08x0.95mm_HandSolder | https://www.electronshik.ru/item/YAG/CC0603FRNPO9BN511
C408 | 1 | 22nF | CC1210KKX7RCBB223 | Capacitor_SMD:C_1210_3225Metric_Pad1.33x2.70mm_HandSolder | https://www.electronshik.ru/item/YAG/CC1210KKX7RCBB223
C409 | 1 | 47nF | GRM43DR73A473KW01L | Capacitor_SMD:C_1812_4532Metric_Pad1.57x3.40mm_HandSolder | https://www.electronshik.ru/item/MUR/GRM43DR73A473KW01L
C415 | 1 | 1pF | GRM1555C1H1R0WA01D | Capacitor_SMD:C_0402_1005Metric_Pad0.74x0.62mm_HandSolder | https://www.electronshik.ru/item/MUR/GRM1555C1H1R0WA01D
D101,D102 | 2 | LED | 150080GS75000,FYLS-0805UBC | LED_SMD:LED_0805_2012Metric_Pad1.15x1.40mm_HandSolder | https://www.electronshik.ru/item/FORYARD/FYLS-0805UBC,https://www.electronshik.ru/item/WURTH/150080GS75000
D201 | 1 | BAS516 | BAS516 | Diode_SMD:D_SOD-523 | https://www.electronshik.ru/item/YJ/BAS516
D202,D203 | 2 | BZT52C18 | BZT52C18 | Diode_SMD:D_SOD-123 | https://www.electronshik.ru/item/DIOTEC/BZT52C18
D204,D205,D206,D207,D208,D209,D210,D211 | 8 | BAV23S | BAV23S | Package_TO_SOT_SMD:SOT-23 | https://www.electronshik.ru/item/NEX-NXP/BAV23S.215
F101 | 1 | MF-MSMF050-2 | MF-MSMF050-2 | Fuse:Fuse_1812_4532Metric_Pad1.30x3.40mm_HandSolder | https://www.electronshik.ru/item/JEMETE/MF-MSMF050-2
FB301 | 1 | BLM18EG121SN1 | BLM18EG121SN1D | Inductor_SMD:L_0603_1608Metric_Pad1.05x0.95mm_HandSolder | https://www.electronshik.ru/item/MUR/BLM18EG121SN1D
J101 | 1 | DX07S024WJ3R400 | DX07S024WJ3R400 | Connector_USB:USB_C_Receptacle_JAE_DX07S024WJ3R400 | https://www.electronshik.ru/item/JAE/DX07S024WJ3R400
J_PMT401 | 1 | PMT
L101,L102 | 2 | 47uH | SRN3015-470M | Inductor_SMD:L_Neosid_SMS-ME3015 | https://www.electronshik.ru/item/BOURNS/SRN3015-470M
L103 | 1 | 100uH | SRU5028-101Y | Inductor_SMD:L_Bourns_SRU5016_5.2x5.2mm | https://www.electronshik.ru/item/BOURNS/SRU5028-101Y
Q201 | 1 | IRLML0040 | IRLML0040 | Package_TO_SOT_SMD:SOT-23 | https://www.electronshik.ru/item/HOTTECH/IRLML0040
Q401,Q402,Q403 | 3 | MMBTA42 | MMBTA42 | Package_TO_SOT_SMD:SOT-23 | https://www.electronshik.ru/item/DIOTEC/MMBTA42
R101,R102 | 2 | 330 | RT0603BRD07330RL | Resistor_SMD:R_0603_1608Metric_Pad0.98x0.95mm_HandSolder | https://www.electronshik.ru/item/YAG/RT0603BRD07330RL
R201 | 1 | 1M | RT0603BRD071ML | Resistor_SMD:R_0603_1608Metric_Pad0.98x0.95mm_HandSolder | https://www.electronshik.ru/item/YAG/RT0603BRD071ML
R202 | 1 | 180k | RC0603FR-07180KL | Resistor_SMD:R_0603_1608Metric_Pad0.98x0.95mm_HandSolder | https://www.electronshik.ru/item/YAG/RC0603FR-07180KL
R203,R220,R231,R232 | 4 | 100k | RC0603FR-07100KL | Resistor_SMD:R_0603_1608Metric_Pad0.98x0.95mm_HandSolder | https://www.electronshik.ru/item/YAG/RC0603FR-07100KL
R204,R302,R303,R304,R305,R307,R309,R314,R408,R411,R413 | 11 | 10k | RC0603FR-0710KL | Resistor_SMD:R_0603_1608Metric_Pad0.98x0.95mm_HandSolder | https://www.electronshik.ru/item/YAG/RC0603FR-0710KL
R205 | 1 | 0.1R | RL0603FR-070R1L | Resistor_SMD:R_0603_1608Metric_Pad0.98x0.95mm_HandSolder | https://www.electronshik.ru/item/YAG/RL0603FR-070R1L
R206,R233 | 2 | 10R | AC0603FR-0710RL | Resistor_SMD:R_0603_1608Metric_Pad0.98x0.95mm_HandSolder | https://www.electronshik.ru/item/YAG/AC0603FR-0710RL
R207,R209,R210,R211,R212,R213,R214,R215,R216,R217 | 10 | 100M | RC1206JR-07100ML | Resistor_SMD:R_1206_3216Metric_Pad1.30x1.75mm_HandSolder | https://www.electronshik.ru/item/YAG/RC1206JR-07100ML
R208 | 1 | 2.2M | RC0603FR-072M2L | Resistor_SMD:R_0603_1608Metric_Pad0.98x0.95mm_HandSolder | https://www.electronshik.ru/item/YAG/RC0603FR-072M2L
R218 | 1 | 1.2k | RC0603FR-071K2L | Resistor_SMD:R_0603_1608Metric_Pad0.98x0.95mm_HandSolder | https://www.electronshik.ru/item/YAG/RC0603FR-071K2L
R219 | 1 | 110k | RC0603FR-07110KL | Resistor_SMD:R_0603_1608Metric_Pad0.98x0.95mm_HandSolder | https://www.electronshik.ru/item/YAG/RC0603FR-07110KL
R221,R222,R223,R224,R225,R226,R227,R228,R229,R230 | 10 | 6.8M | RC1206FR-076M8L | Resistor_SMD:R_1206_3216Metric_Pad1.30x1.75mm_HandSolder | https://www.electronshik.ru/item/YAG/RC1206FR-076M8L
R301 | 1 | R330 | RC0603FR-07330RL | Resistor_SMD:R_0603_1608Metric_Pad0.98x0.95mm_HandSolder | https://www.electronshik.ru/item/YAG/RC0603FR-07330RL
R306,R308 | 2 | 1k | RC0603FR-071KL | Resistor_SMD:R_0603_1608Metric_Pad0.98x0.95mm_HandSolder | https://www.electronshik.ru/item/YAG/RC0603FR-071KL
R310 | 1 | 22k | RC0603FR-0722KL | Resistor_SMD:R_0603_1608Metric_Pad0.98x0.95mm_HandSolder | https://www.electronshik.ru/item/YAG/RC0603FR-0722KL
R311 | 1 | 5.9k | RC0603FR-075K9L | Resistor_SMD:R_0603_1608Metric_Pad0.98x0.95mm_HandSolder | https://www.electronshik.ru/item/YAG/RC0603FR-075K9L
R312 | 1 | 8.2k | RC0603FR-078K2L | Resistor_SMD:R_0603_1608Metric_Pad0.98x0.95mm_HandSolder | https://www.electronshik.ru/item/YAG/RC0603FR-078K2L
R313 | 1 | 2k | RC0603FR-072KL | Resistor_SMD:R_0603_1608Metric_Pad0.98x0.95mm_HandSolder | https://www.electronshik.ru/item/YAG/RC0603FR-072KL
R401,R402 | 2 | 750k | RC1206FR-07750KL | Resistor_SMD:R_1206_3216Metric_Pad1.30x1.75mm_HandSolder | https://www.electronshik.ru/item/YAG/RC1206FR-07750KL
R403,R404,R405,R406,R407 | 5 | 680k | RC1206FR-07680KL | Resistor_SMD:R_1206_3216Metric_Pad1.30x1.75mm_HandSolder | https://www.electronshik.ru/item/YAG/RC1206FR-07680KL
R409 | 1 | 820k | RC1206FR-07820KL | Resistor_SMD:R_1206_3216Metric_Pad1.30x1.75mm_HandSolder | https://www.electronshik.ru/item/YAG/RC1206FR-07820KL
R410,R412 | 2 | 1M | RC1206FR-071ML | Resistor_SMD:R_1206_3216Metric_Pad1.30x1.75mm_HandSolder | https://www.electronshik.ru/item/YAG/RC1206FR-071ML
R415 | 1 | 49.9 | RC0603FR-0749R9L | Resistor_SMD:R_0603_1608Metric_Pad0.98x0.95mm_HandSolder | https://www.electronshik.ru/item/YAG/RC0603FR-0749R9L
R416 | 1 | 100 | RC0603FR-07100RL | Resistor_SMD:R_0603_1608Metric_Pad0.98x0.95mm_HandSolder | https://www.electronshik.ru/item/YAG/RC0603FR-07100RL
R417 | 1 | 1.5k | RC0603FR-071K5L | Resistor_SMD:R_0603_1608Metric_Pad0.98x0.95mm_HandSolder | https://www.electronshik.ru/item/YAG/RC0603FR-071K5L
R_CC101,R_CC102 | 2 | 5.1k | RC0603FR-075K1L | Resistor_SMD:R_0603_1608Metric_Pad0.98x0.95mm_HandSolder | https://www.electronshik.ru/item/YAG/RC0603FR-075K1L
T201 | 1 | ATB322524-0110-T000 | ATB322524-0110-T000 | посадочные места:CHOKE_524-0110-T000_TDK-M | https://www.chipdip.ru/product/atb322524-0110-t000-md-power-transformator-tdk-8048099667
U101 | 1 | LP5907MFX-3.3 | LP5907MFX-3.3 | Package_TO_SOT_SMD:SOT-23-5 | https://www.electronshik.ru/item/TECH%20PUB/LP5907MFX-3.3
U102 | 1 | AMS1117-3.3 | AMS1117-3.3 | Package_TO_SOT_SMD:SOT-223-3_TabPin2 | https://www.electronshik.ru/item/YOUTAI/AMS1117-3.3
U103 | 1 | FT231XQ | FT231XQ | Package_DFN_QFN:QFN-20-1EP_4x4mm_P0.5mm_EP2.5x2.5mm | https://www.chipdip.ru/product/ft231xq-r-interfeys-usb-full-uart-kol-vo-vyvodov-cbus-ftdi-8048314966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
U104 | 1 | TPS60400DBV | TPS60400DBV | Package_TO_SOT_SMD:SOT-23-5 | https://www.chipdip.ru/product/tps60400dbvr-generatory-podkachki-zaryada-texas-instruments-9020005566
U201 | 1 | max1847eee+ | max1847eee+ | посадочные места:21-0055H_16_MXM-M | https://ali.click/or9lc1t
U202,U301 | 2 | TL431 | TL431 | Package_TO_SOT_SMD:SOT-23 | https://www.electronshik.ru/item/YOUTAI/TL431
U302 | 1 | STM32G474MET6 | STM32G474MET6 | Package_QFP:LQFP-80_12x12mm_P0.5mm | https://www.electronshik.ru/item/ST/STM32G474MET6
U303 | 1 | W25Q64JVSSIQ | W25Q64JVSSIQ | посадочные места:SOIC-8_5P28X5P28_WIN-M | https://www.chipdip.ru/product/w25q64jvssiq-mikroshema-pamyati-flash-64mbit-8m-x-8-winbond-9000601462
U401 | 1 | AD8000YRDZ-REEL | AD8000YRDZ-REEL | посадочные места:RD_8_1_ADI-M | https://www.electronshik.ru/item/AD/AD8000YRDZ-REEL7
U_ESD101 | 1 | PRTR5V0U2X | PRTR5V0U2X | Package_TO_SOT_SMD:SOT-143 | https://www.electronshik.ru/item/YOUTAI/PRTR5V0U2X
Y301 | 1 | ABM8G-16.000MHZ-4Y-T3 | ABM8G-16.000MHZ-4Y-T3 | Crystal:Crystal_SMD_3225-4Pin_3.2x2.5mm | https://www.electronshik.ru/item/ABRACON/ABM8G-16.000MHZ-4Y-T3

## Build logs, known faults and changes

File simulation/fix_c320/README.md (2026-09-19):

# fix_c320 — варианты исправления находок 1.1 и 1.3 (2026-09-15)

Источник находок: `review/REVIEW_critic_2026-09-15.md`.

- **1.1** — `C320` (100 нФ на GND) сидит прямо на `PB0` вместе с разделительным `C314` (100 нФ) →
  ёмкостный делитель ×0.5 на входе OPAMP3. Старые деки прятали `C320` за резистором `Rbias 4.65k`,
  которого в схеме нет.
- **1.3** — разделительные цепи `C317`/`R308` и `C314`/(`R310‖R311`) имеют τ ≈ 0.1–0.2 мс, а не «16 Гц»
  из дока → хвосты импульсов, зависящие от загрузки.

## Запуск

```
python simulation/fix_c320/run_spice.py          # деки + LTspice (14 шт., ~45 с) + таблица
simulation\fix_c320\build_dsp.cmd                # firmware/core/dsp.c -> out/dsp_shim.dll (MSVC x64)
python simulation/fix_c320/mc.py --phase-lock    # Монте-Карло, фаза привязана к отсчёту
python simulation/fix_c320/mc.py                 # то же со случайной фазой
```

Всё сгенерированное — в `out/` (игнорируется git).

## Методика

1. **LTspice, транзиент 30 мс** на импульс Cs-137 (0.94 мА, как в `sim_bias_fixed.cir`) — топология по
   нетлисту, TIA поведенческий (+499·I, τ = 2.35 нс). Длинное окно нужно, чтобы увидеть хвосты.
2. **LTspice, `.noise`** до 2 МГц (Найквист при 4 Мвыб/с) — официальная модель ADA4817 + `opamp_g474_noise`.
3. **Монте-Карло**: пуассоновский поток 1/10/30 кимп/с, спектр амплитуд — inverse-CDF Cs-137 из
   `firmware/core/pulsegen.c` (фотопик → дельта, 23.8 % событий), шум с PSD из п. 2, АЦП 12 бит
   @4 Мвыб/с, VREF 2.5 В → **настоящий `dsp.c` прошивки** (порог 25 кодов при полном усилении,
   `min_width=2`, `fit_m=2`). Метрика — FWHM электронной части фотопика (без статистики сцинтиллятора).
4. **Кэмпбелл** — независимая аналитическая оценка флуктуаций базовой линии от хвостов.
5. **Допуски** — Монте-Карло рабочей точки АЦП: смещения ОУ ±3 мВ, резисторы ±1 %, REF35 ±0.05 %,
   PGA ±1 % (допущение: в DS12288 норма на ошибку усиления PGA не найдена).

Контроль модели: вариант `Vdoc` (старая топология) даёт **1159 каналов** — ровно цифра из доков.

## Варианты

| | Изменение в схеме | τ C317 | τ C314 |
|---|---|---|---|
| **V0** | как сейчас | 100 мкс | 175 мкс |
| **V1** | удалить `C320` | 100 мкс | 87 мкс |
| **V2** | удалить `C320`; `C317`, `C314` → 1 мкФ | 1.0 мс | 0.87 мс |
| **V3** | `C320` оставить; `Rs` 10 кОм между узлом делителя B и `PB0`; `C317` → 1 мкФ | 1.0 мс | 1.0 мс |
| **V4** | убрать `C317`/`C314` (DC-связь); OPAMP3 в режиме PGA ×4 с опорой на `VINM0`=`PB2` (1.62к/976 от VREF + 100 нФ) | — | — |

## Результаты

### Транзиент и шум (LTspice)

| | Cs-137 на АЦП | канал | базовая линия | до VREF @3.5 МэВ | выброс | шум | σ, кан |
|---|---|---|---|---|---|---|---|
| Vdoc (контроль) | 353.6 мВ | 1159 | 0.409 В | +0.222 В | −5.4 % | 77.6 мкВ | 0.25 |
| **V0** | **176.7 мВ** | **579** | 0.409 В | +1.157 В | −5.6 % | 65.1 мкВ | 0.21 |
| V1 | 352.9 мВ | 1156 | 0.409 В | +0.225 В | −6.0 % | 77.5 мкВ | 0.25 |
| V2 | 354.3 мВ | 1161 | 0.409 В | +0.218 В | −4.7 % | 77.7 мкВ | 0.25 |
| V3 | 354.3 мВ | 1161 | 0.409 В | +0.218 В | −4.7 % | 77.7 мкВ | 0.25 |
| V4 | 354.5 мВ | 1162 | 0.431 В | +0.195 В | −4.6 % | 77.7 мкВ | 0.25 |

Выходы OPAMP1/OPAMP2 на 3.5 МэВ во всех вариантах в окне 0.10…3.20 В (OPAMP1 0.57…2.52 В).

### Электронное FWHM фотопика Cs-137 (Монте-Карло, `--phase-lock`, настоящий `dsp.c`)

| | 10 кимп/с | 30 кимп/с | сдвиг пика @30к |
|---|---|---|---|
| V0 | 0.64 % | 1.03 % | +0.33 % |
| V1 | 0.54 % | **1.29 %** | +0.19 % |
| **V2** | **0.20 %** | **0.20 %** | +0.21 % |
| V3 | 0.20 % | 0.19 % | +0.21 % |
| V4 | 0.16 % | 0.23 % | +0.06 % |

На 1 кимп/с все варианты ниже разрешения выхода детектора (1 канал ≈ 0.1 %).
Для масштаба: собственное разрешение NaI(Tl) на 662 кэВ ≈ 7 % FWHM; 1.29 % в квадратуре ухудшают его
до 7.12 % (+1.7 % относительно), 0.20 % — до 7.003 %.

Кэмпбелл (σ базовой линии от хвостов позже 30 мкс, 30 кимп/с, без трекера): V0/V1 0.48 %, V2/V3 0.24 %,
V4 0.02 % — тот же порядок и та же сортировка.

### Допуски рабочей точки АЦП (худший случай из 200 000 розыгрышей)

| | базовая линия | запас до VREF @3.5 МэВ | запас до VOLSAT снизу |
|---|---|---|---|
| V1/V2/V3 (AC) | 0.375…0.420 В | ≥ +0.210 В | ≥ +0.275 В |
| V4 (DC) | 0.182…0.582 В | ≥ **+0.048 В** | ≥ +0.082 В (с выбросом 4.6 % — упор) |

## Вывод

1. **1.1 подтверждена симуляцией и обязательна к исправлению**: схема как есть даёт ровно половину
   амплитуды (579 каналов вместо 1159).
2. **Рекомендация — V2**: удалить `C320`, `C317` и `C314` заменить на 1 мкФ X7R. Новых цепей нет,
   трассировка не меняется; лечит 1.1 и 1.3 одновременно (электронное FWHM не зависит от загрузки).
   ⚠ В BOM 1 мкФ есть только в 0805 (`CC0805JKX7R9BB105`), а посадки `C314`/`C317` — 0603:
   либо новый MPN 1 мкФ X7R 0603, либо смена посадки на разведённой плате МК.
   Постоянное напряжение на `C317` ≈ 0.8 В, на `C314` ≈ 1.5 В — DC-bias X7R меняет только τ, не усиление.
3. **V3** равноценна по характеристикам, но требует нового резистора и правки трассировки у `PB0`.
4. **V1** (только удалить `C320`) лечит 1.1, но не 1.3: при 30 кимп/с электронное FWHM ×6.
5. **V4** лучшая по хвостам, но **не рекомендуется** без подстройки на каждой плате: разброс базовой
   линии ±0.2 В съедает запас сверху до 48 мВ.

## Попутные находки

- **Ветка тестового ЦАП `C318`+`R307` (PA4)**: при включённом ЦАП с буфером усиление падает до ×0.887
  и меняется форма импульса (вариант `V1d` в `run_spice.py`). По DS12288 выходное сопротивление ЦАП
  без буфера 9.6…13.8 кОм — тоже нагружает узел. **На время набора спектра ЦАП выключать, PA4 — аналоговый
  вход (Hi-Z).**
- **DSP на боевом импульсе** (FWHM ≈ 2.3 отсчёта @4 Мвыб/с, `fit_m=2`): парабола по 5 точкам занижает пик
  на 12–15 % и даёт фазовый разброс σ ≈ 3 % (FWHM ≈ 7.4 %, сопоставимо с NaI) — при случайной фазе прихода
  (`mc.py` без флага). К находке 5.1 ревью: алгоритм оценки амплитуды нужно переработать до этапа 3.

## Ограничения

- Модель ОУ G474 не ограничена рейлами — клиппинг оценивается по запасам, а не моделируется.
- TIA в транзиенте поведенческий; паразитные ёмкости разводки не учтены.
- Ядро отклика обрезано на 30 мс (τ до 1 мс — хвост к этому времени < 10⁻¹²).
- Шум гауссов с PSD из моделей; 1/f шум ОУ G474 модель не содержит.
- Частота АЦП 4 Мвыб/с по ТЗ; текущая прошивка Nucleo работает на 2.83 Мвыб/с.

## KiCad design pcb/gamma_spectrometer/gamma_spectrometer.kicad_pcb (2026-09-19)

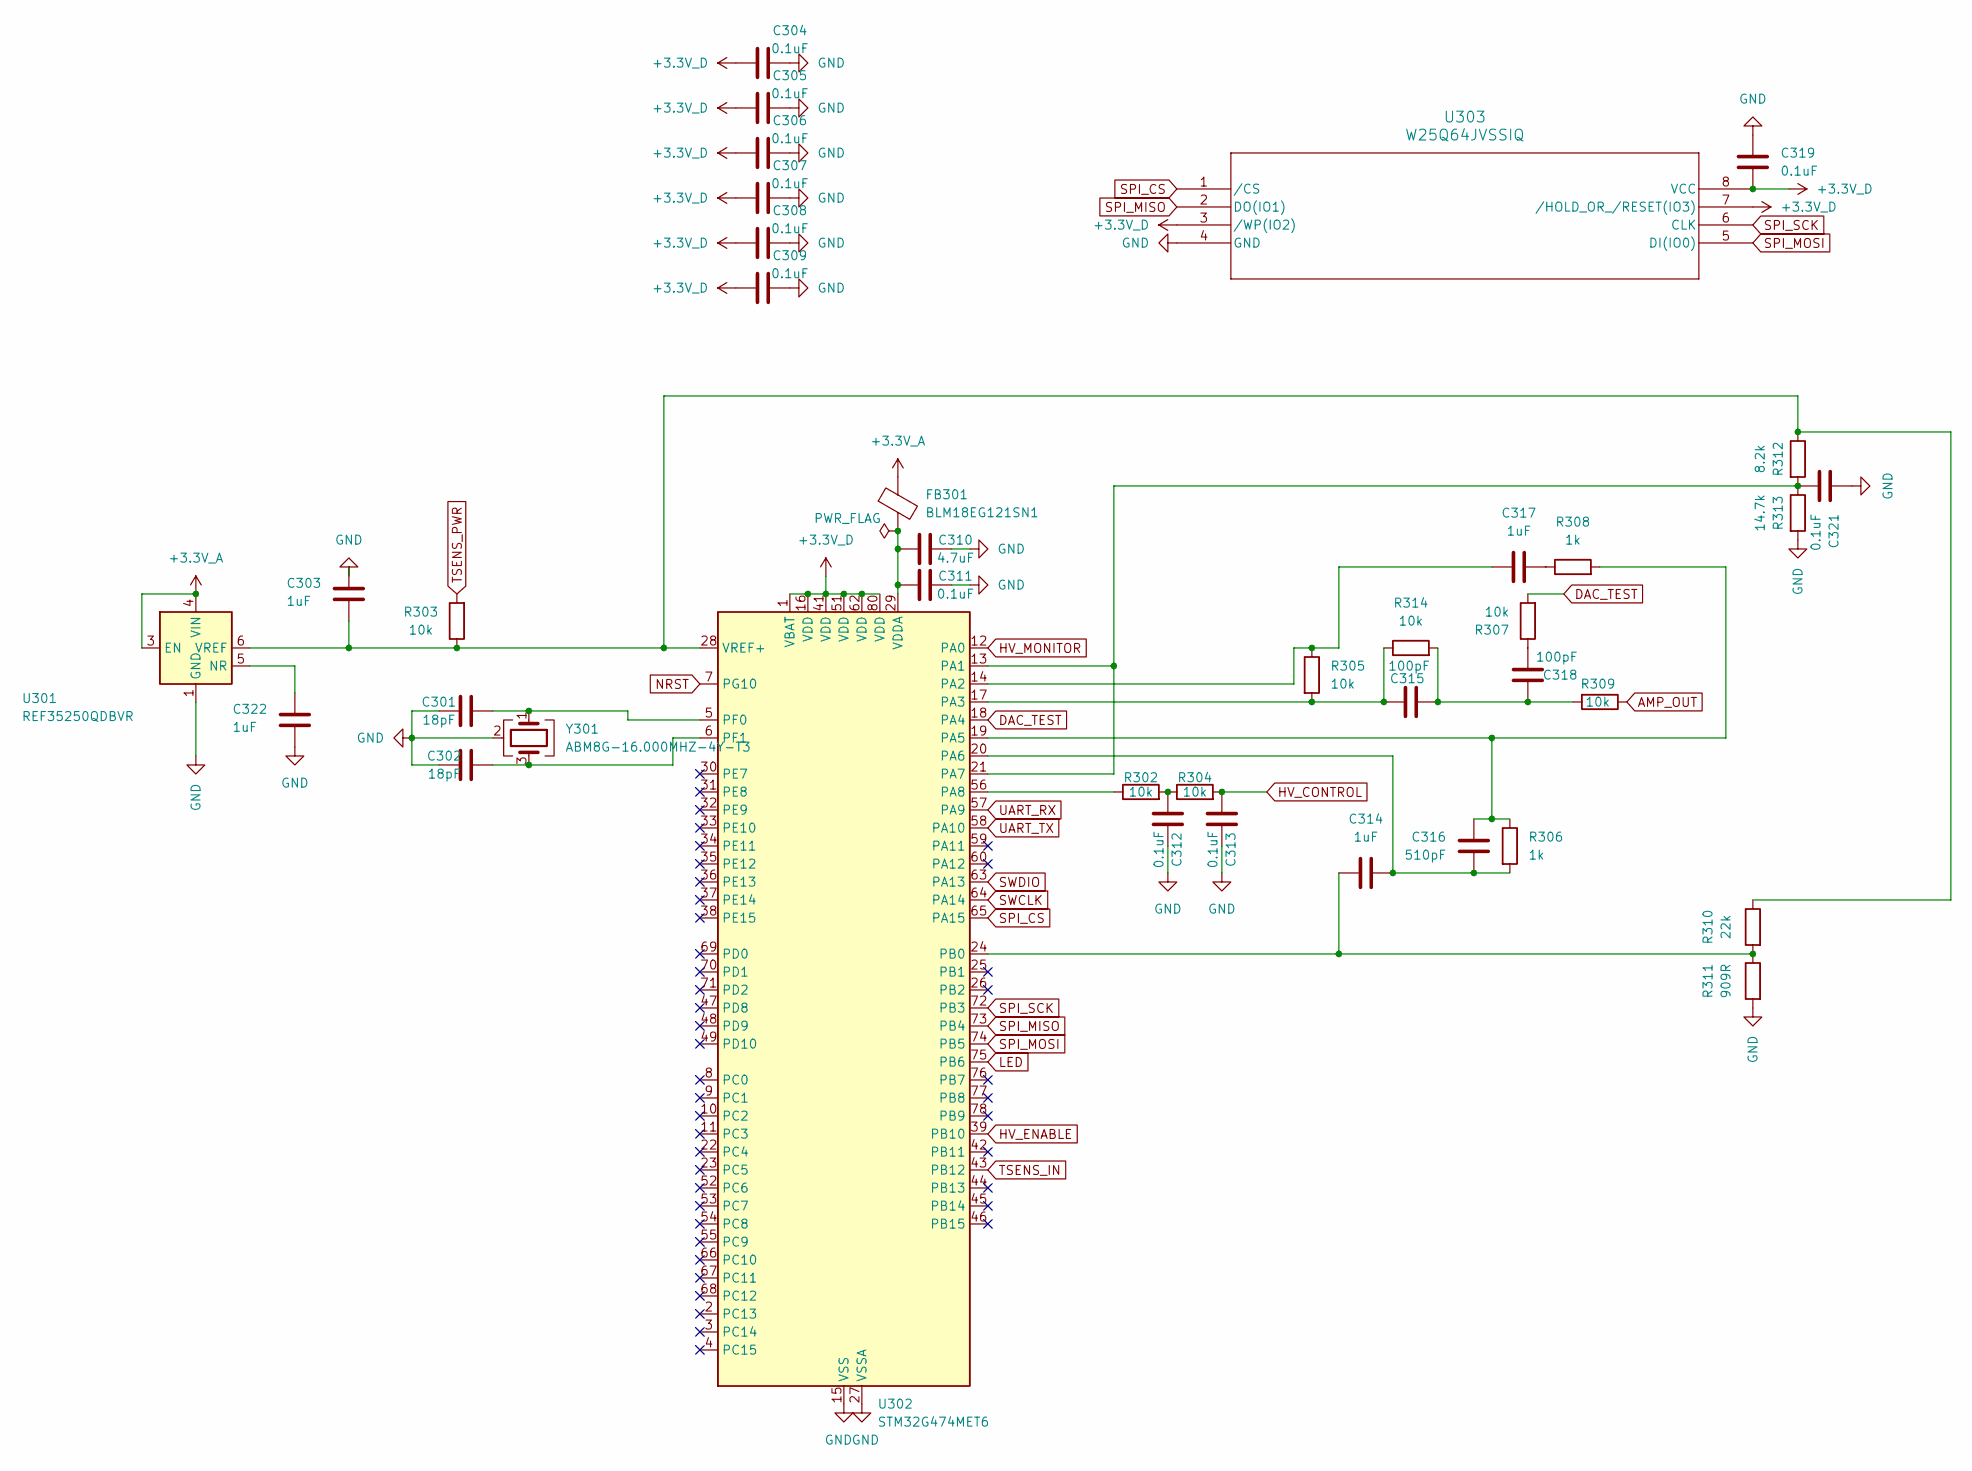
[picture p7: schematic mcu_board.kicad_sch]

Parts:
C301, C302: 18pF; C_0402_1005Metric_Pad0.74x0.62mm_HandSolder
C303, C322: 1uF; C_0805_2012Metric_Pad1.18x1.45mm_HandSolder
C304, C305, C306, C307, C308, C309, C311, C312, C313, C319, C321: 0.1uF; C_0603_1608Metric_Pad1.08x0.95mm_HandSolder
C310: 4.7uF; C_0805_2012Metric_Pad1.18x1.45mm_HandSolder
C314, C317: 1uF; C_0603_1608Metric_Pad1.08x0.95mm_HandSolder
C315, C318: 100pF; C_0603_1608Metric_Pad1.08x0.95mm_HandSolder
C316: 510pF; C_0603_1608Metric_Pad1.08x0.95mm_HandSolder
FB301: BLM18EG121SN1; L_0603_1608Metric_Pad1.05x0.95mm_HandSolder
R302, R303, R304, R305, R307, R309, R314: 10k; R_0603_1608Metric_Pad0.98x0.95mm_HandSolder
R306, R308: 1k; R_0603_1608Metric_Pad0.98x0.95mm_HandSolder
R310: 22k; R_0603_1608Metric_Pad0.98x0.95mm_HandSolder
R311: 909R; R_0603_1608Metric_Pad0.98x0.95mm_HandSolder
R312: 8.2k; R_0603_1608Metric_Pad0.98x0.95mm_HandSolder
R313: 14.7k; R_0603_1608Metric_Pad0.98x0.95mm_HandSolder
U301: REF35250QDBVR; SOT-23-6
U302: STM32G474MET6; LQFP-80_12x12mm_P0.5mm
U303: W25Q64JVSSIQ; SOIC-8_5P28X5P28_WIN-M
Y301: ABM8G-16.000MHZ-4Y-T3; Crystal_SMD_3225-4Pin_3.2x2.5mm

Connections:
+3.3V_A: FB301.1, U301.3 (EN), U301.4 (VIN); also elsewhere on the board
+3.3V_D: C304.1, C305.1, C306.1, C307.1, C308.1, C309.1, C319.2, U302.1 (VBAT), U302.16 (VDD), U302.41 (VDD), U302.51 (VDD), U302.62 (VDD), U302.80 (VDD), U303.3 (/WP(IO2)), U303.7 (/HOLD_OR_/RESET(IO3)), U303.8 (VCC); also elsewhere on the board
AMP_OUT: R309.1; also elsewhere on the board
DAC_TEST: R307.2, U302.18 (PA4)
GND: C301.2, C302.2, C303.1, C304.2, C305.2, C306.2, C307.2, C308.2, C309.2, C310.2, C311.2, C312.2, C313.2, C319.1, C321.1, C322.2, R311.2, R313.2, U301.1 (GND), U301.2 (GND), U302.15 (VSS), U302.27 (VSSA), U302.40 (VSS), U302.50 (VSS), U302.61 (VSS), U302.79 (VSS), U303.4 (GND), Y301.2 (G), Y301.4 (G); also elsewhere on the board
HV_CONTROL: C313.1, R304.2; also elsewhere on the board
HV_ENABLE: U302.39 (PB10); also elsewhere on the board
HV_MONITOR: U302.12 (PA0); also elsewhere on the board
LED: U302.75 (PB6); also elsewhere on the board
NRST: U302.7 (PG10)
unnamed: C312.1, R302.2, R304.1
unnamed: C315.1, C318.1, R309.2, R314.2
unnamed: C317.2, R308.1
unnamed: C318.2, R307.1
unnamed: C322.1, U301.5 (NR)
unnamed: C303.2, R303.1, R310.1, R312.1, U301.6 (VREF), U302.28 (VREF+)
unnamed: C321.2, R312.2, R313.1, U302.13 (PA1), U302.21 (PA7)
unnamed: C317.1, R305.1, U302.14 (PA2)
unnamed: C315.2, R305.2, R314.1, U302.17 (PA3)
unnamed: C316.1, R306.1, R308.2, U302.19 (PA5)
unnamed: C314.2, C316.2, R306.2, U302.20 (PA6)
unnamed: R302.1, U302.56 (PA8)
unnamed: C314.1, R310.2, R311.1, U302.24 (PB0)
unnamed: C301.1, U302.5 (PF0), Y301.1
unnamed: C302.1, U302.6 (PF1), Y301.3
unnamed: C310.1, C311.1, FB301.2, U302.29 (VDDA)
SPI_CS: U302.65 (PA15), U303.1 (/CS)
SPI_MISO: U302.73 (PB4), U303.2 (DO(IO1))
SPI_MOSI: U302.74 (PB5), U303.5 (DI(IO0))
SPI_SCK: U302.72 (PB3), U303.6 (CLK)
SWCLK: U302.64 (PA14)
SWDIO: U302.63 (PA13)
TSENS_IN: U302.43 (PB12); also elsewhere on the board
TSENS_PWR: R303.2; also elsewhere on the board
UART_RX: U302.57 (PA9); also elsewhere on the board
UART_TX: U302.58 (PA10); also elsewhere on the board

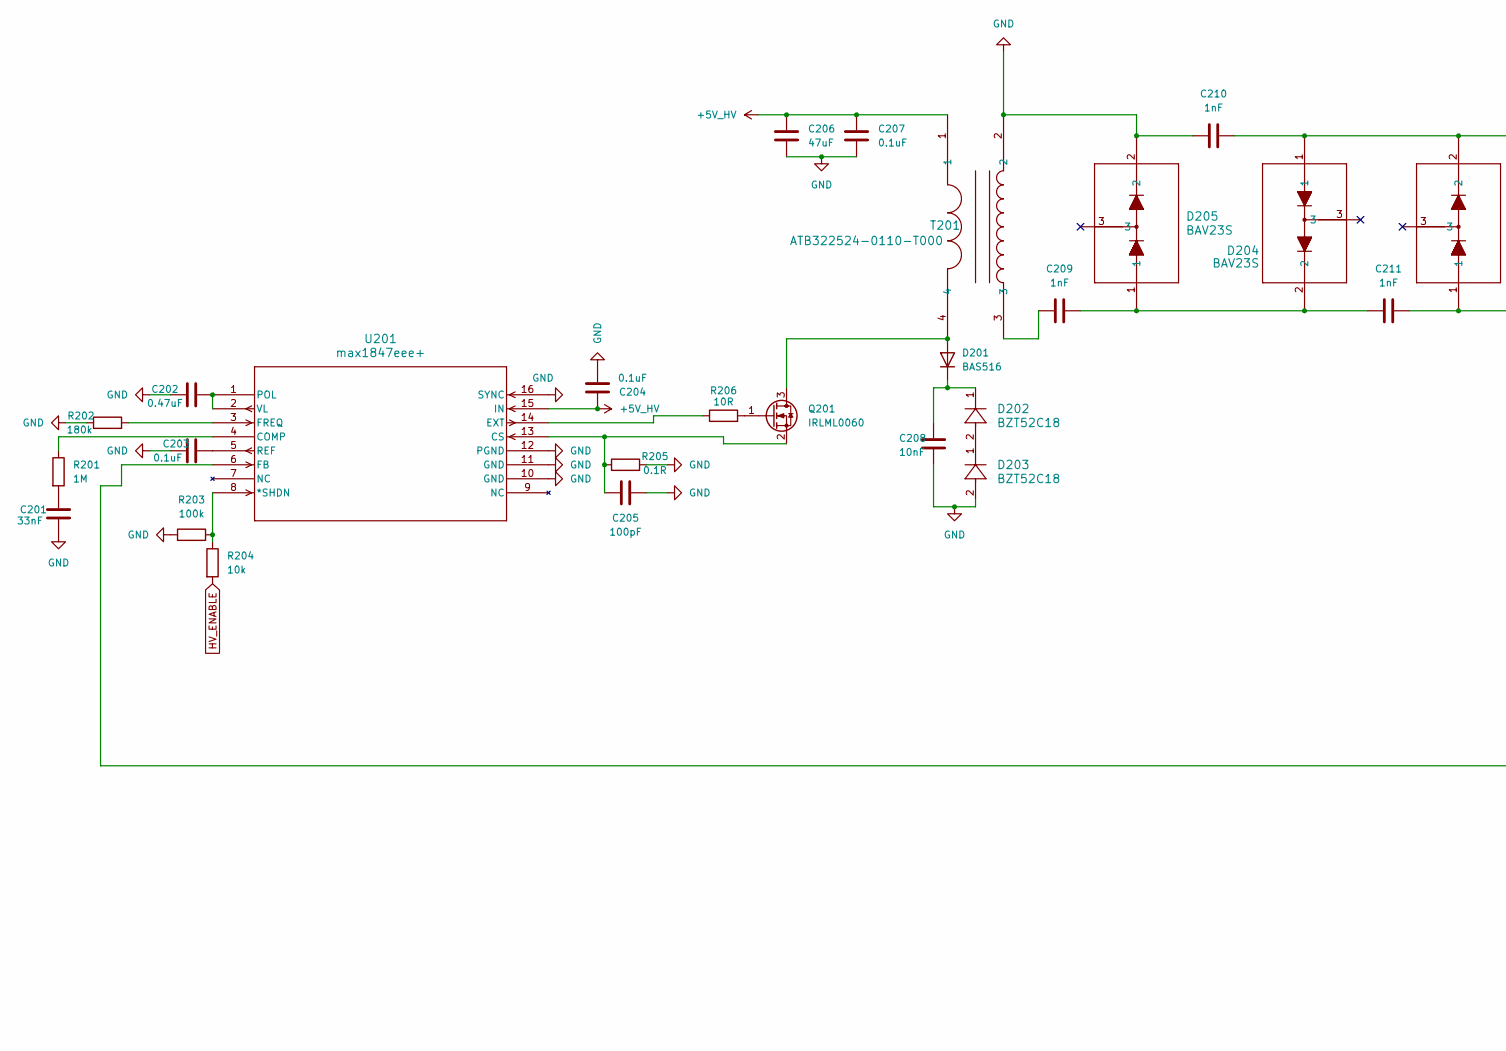
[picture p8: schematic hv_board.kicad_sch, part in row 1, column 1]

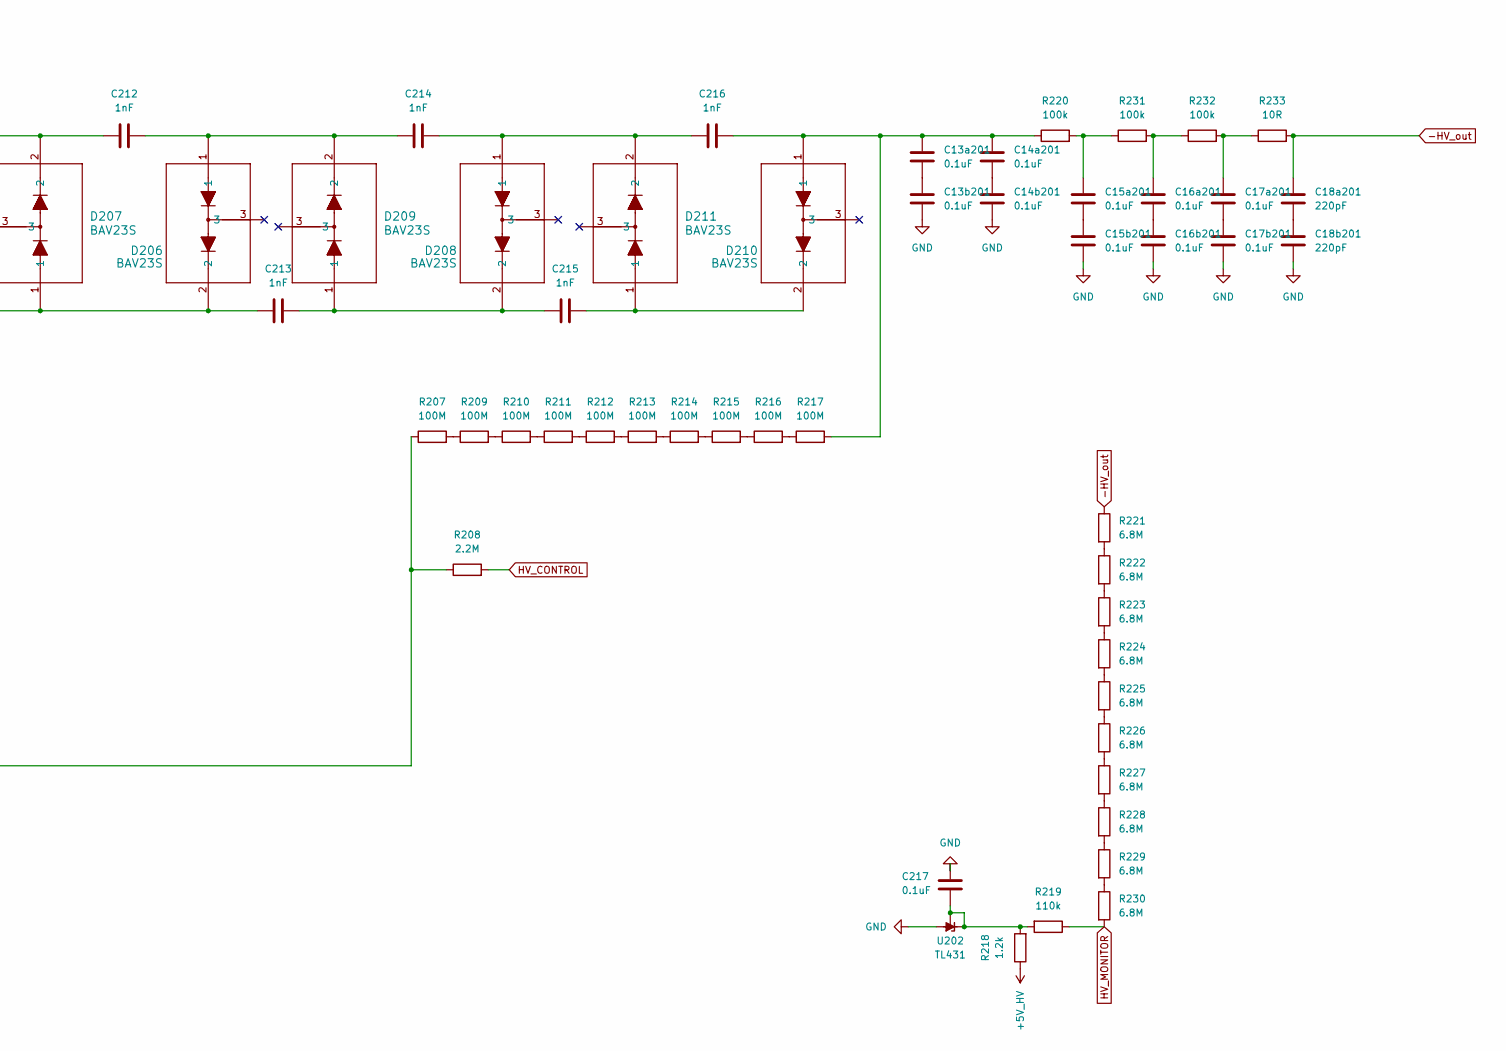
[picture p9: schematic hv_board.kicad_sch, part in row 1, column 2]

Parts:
C13a201, C13b201, C14a201, C14b201, C15a201, C15b201, C16a201, C16b201, C17a201, C17b201: 0.1uF; C_1812_4532Metric_Pad1.57x3.40mm_HandSolder
C18a201, C18b201: 220pF; C_1206_3216Metric_Pad1.33x1.80mm_HandSolder
C201: 33nF; C_0805_2012Metric_Pad1.18x1.45mm_HandSolder
C202: 0.47uF; C_0805_2012Metric_Pad1.18x1.45mm_HandSolder
C203, C204, C207, C217: 0.1uF; C_0603_1608Metric_Pad1.08x0.95mm_HandSolder
C205: 100pF; C_0603_1608Metric_Pad1.08x0.95mm_HandSolder
C206: 47uF; C_1210_3225Metric_Pad1.33x2.70mm_HandSolder
C208: 10nF; C_0603_1608Metric_Pad1.08x0.95mm_HandSolder
C209, C210, C211, C212, C213, C214, C215, C216: 1nF; C_0805_2012Metric_Pad1.18x1.45mm_HandSolder
D201: BAS516; D_SOD-523
D202, D203: BZT52C18; D_SOD-123
D204, D205, D206, D207, D208, D209, D210, D211: BAV23S; SOT-23
Q201: IRLML0060; SOT-23
R201: 1M; R_0603_1608Metric_Pad0.98x0.95mm_HandSolder
R202: 180k; R_0603_1608Metric_Pad0.98x0.95mm_HandSolder
R203, R220, R231, R232: 100k; R_0603_1608Metric_Pad0.98x0.95mm_HandSolder
R204: 10k; R_0603_1608Metric_Pad0.98x0.95mm_HandSolder
R205: 0.1R; R_0603_1608Metric_Pad0.98x0.95mm_HandSolder
R206, R233: 10R; R_0603_1608Metric_Pad0.98x0.95mm_HandSolder
R207, R209, R210, R211, R212, R213, R214, R215, R216, R217: 100M; R_1206_3216Metric_Pad1.30x1.75mm_HandSolder
R208: 2.2M; R_0603_1608Metric_Pad0.98x0.95mm_HandSolder
R218: 1.2k; R_0603_1608Metric_Pad0.98x0.95mm_HandSolder
R219: 110k; R_0603_1608Metric_Pad0.98x0.95mm_HandSolder
R221, R222, R223, R224, R225, R226, R227, R228, R229, R230: 6.8M; R_1206_3216Metric_Pad1.30x1.75mm_HandSolder
T201: ATB322524-0110-T000; CHOKE_524-0110-T000_TDK-M
U201: max1847eee+; 21-0055H_16_MXM-M
U202: TL431; SOT-23

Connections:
+5V_HV: C204.2, C206.1, C207.1, R218.1, T201.1, U201.15 (IN); also elsewhere on the board
GND: C13b201.2, C14b201.2, C15b201.2, C16b201.2, C17b201.2, C18b201.2, C201.2, C202.1, C203.1, C204.1, C205.2, C206.2, C207.2, C208.2, C210.1, C217.1, D203.2, D205.2, R202.1, R203.2, R205.2, T201.2, U201.10 (GND), U201.11 (GND), U201.12 (PGND), U201.16 (SYNC), U202.3 (A); also elsewhere on the board
HV_CONTROL: R208.2; also elsewhere on the board
HV_ENABLE: R204.2; also elsewhere on the board
HV_MONITOR: R219.1, R230.2; also elsewhere on the board
unnamed: C13a201.1, C14a201.1, C216.2, D210.1, R217.2, R220.1
unnamed: C13a201.2, C13b201.1
unnamed: C14a201.2, C14b201.1
unnamed: C15a201.1, R220.2, R231.1
unnamed: C15a201.2, C15b201.1
unnamed: C16a201.1, R231.2, R232.1
unnamed: C16a201.2, C16b201.1
unnamed: C17a201.1, R232.2, R233.1
unnamed: C17a201.2, C17b201.1
unnamed: C18a201.2, C18b201.1
unnamed: C201.1, R201.2
unnamed: C209.1, T201.3
unnamed: C209.2, C211.1, D204.2, D205.1
unnamed: C210.2, C212.1, D204.1, D207.2
unnamed: C211.2, C213.1, D206.2, D207.1
unnamed: C212.2, C214.1, D206.1, D209.2
unnamed: C213.2, C215.1, D208.2, D209.1
unnamed: C214.2, C216.1, D208.1, D211.2
unnamed: C215.2, D210.2, D211.1
unnamed: D201.2 (A), Q201.3 (D), T201.4
unnamed: C208.1, D201.1 (K), D202.1
unnamed: D202.2, D203.1
unnamed: Q201.1 (G), R206.2
unnamed: C205.1, Q201.2 (S), R205.1, U201.13 (CS)
unnamed: R207.2, R209.1
unnamed: R209.2, R210.1
unnamed: R210.2, R211.1
unnamed: R211.2, R212.1
unnamed: R212.2, R213.1
unnamed: R213.2, R214.1
unnamed: R214.2, R215.1
unnamed: R215.2, R216.1
unnamed: R216.2, R217.1
unnamed: R221.2, R222.1
unnamed: R222.2, R223.1
unnamed: R223.2, R224.1
unnamed: R224.2, R225.1
unnamed: R225.2, R226.1
unnamed: R226.2, R227.1
unnamed: R227.2, R228.1
unnamed: R228.2, R229.1
unnamed: R229.2, R230.1
unnamed: R203.1, R204.1, U201.8 (*SHDN)
unnamed: R201.1, U201.4 (COMP)
unnamed: R206.1, U201.14 (EXT)
unnamed: R207.1, R208.1, U201.6 (FB)
unnamed: R202.2, U201.3 (FREQ)
unnamed: C202.2, U201.1 (POL), U201.2 (VL)
unnamed: C203.2, U201.5 (REF)
unnamed: C217.2, R218.2, R219.2, U202.1 (K), U202.2 (REF)
−HV_out: C18a201.1, R221.1, R233.2; also elsewhere on the board

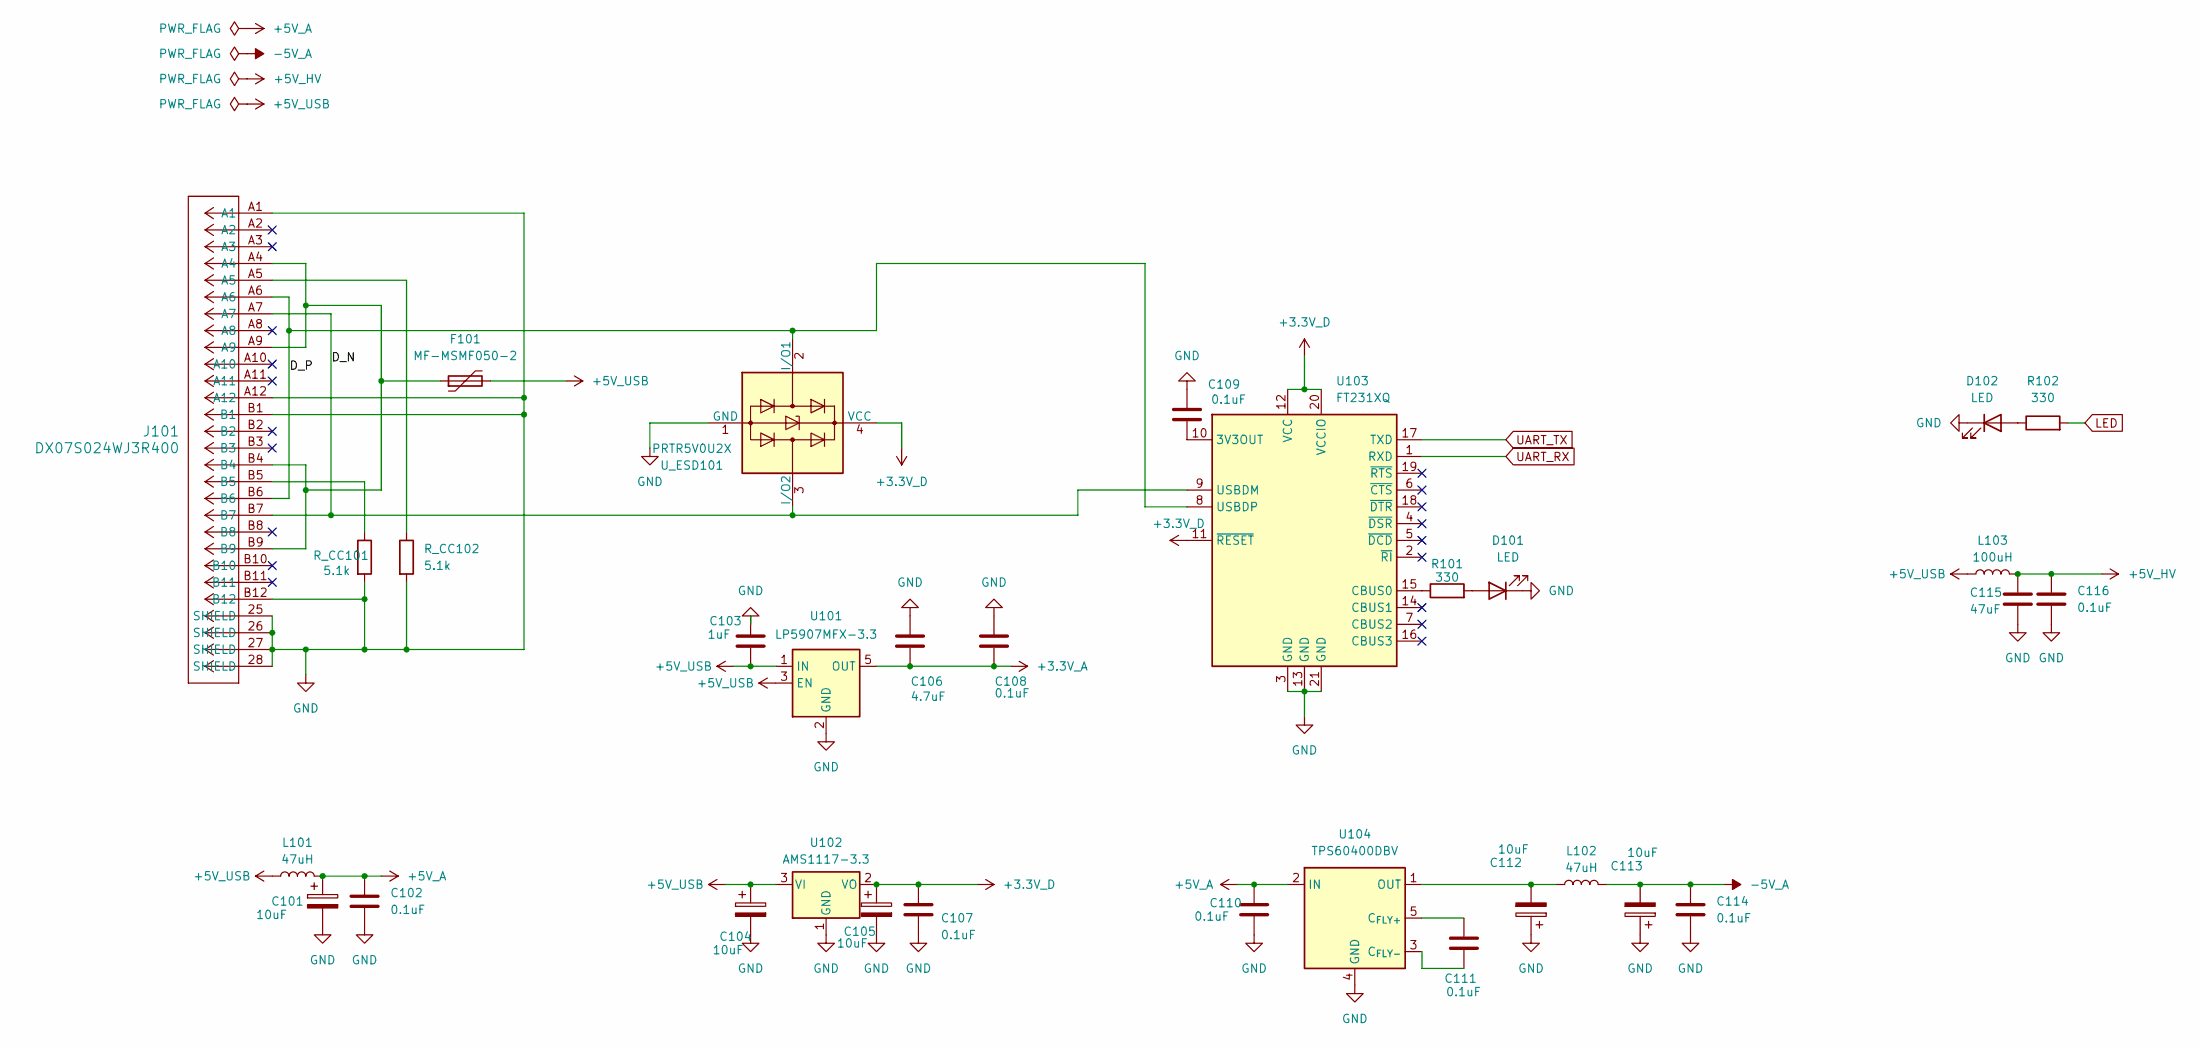
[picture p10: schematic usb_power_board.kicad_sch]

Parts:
C101, C104, C105, C112, C113: 10uF; CP_EIA-3528-21_Kemet-B_HandSolder
C102, C107, C108, C109, C110, C111, C114, C116: 0.1uF; C_0603_1608Metric_Pad1.08x0.95mm_HandSolder
C103: 1uF; C_0805_2012Metric_Pad1.18x1.45mm_HandSolder
C106: 4.7uF; C_0805_2012Metric_Pad1.18x1.45mm_HandSolder
C115: 47uF; C_1210_3225Metric_Pad1.33x2.70mm_HandSolder
D101, D102: LED; LED_0805_2012Metric_Pad1.15x1.40mm_HandSolder
F101: MF-MSMF050-2; Fuse_1812_4532Metric_Pad1.30x3.40mm_HandSolder
J101: DX07S024WJ3R400; USB_C_Receptacle_JAE_DX07S024WJ3R400
L101, L102: 47uH; L_Neosid_SMS-ME3015
L103: 100uH; L_Bourns_SRU5016_5.2x5.2mm
R101, R102: 330; R_0603_1608Metric_Pad0.98x0.95mm_HandSolder
R_CC101, R_CC102: 5.1k; R_0603_1608Metric_Pad0.98x0.95mm_HandSolder
U101: LP5907MFX-3.3; SOT-23-5
U102: AMS1117-3.3; SOT-223-3_TabPin2
U103: FT231XQ; QFN-20-1EP_4x4mm_P0.5mm_EP2.5x2.5mm
U104: TPS60400DBV; SOT-23-5
U_ESD101: PRTR5V0U2X; SOT-143

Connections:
+3.3V_A: C106.2, C108.2, U101.5 (OUT); also elsewhere on the board
+3.3V_D: C105.1, C107.1, U102.2 (VO), U103.11 (~RESET), U103.12 (VCC), U103.20 (VCCIO), U_ESD101.4 (VCC); also elsewhere on the board
+5V_A: C101.1, C102.1, C110.1, L101.2, U104.2 (IN); also elsewhere on the board
+5V_HV: C115.1, C116.1, L103.2; also elsewhere on the board
+5V_USB: C103.2, C104.1, F101.2, L101.1, L103.1, U101.1 (IN), U101.3 (EN), U102.3 (VI)
/USB_Power_Board/D_N: J101.A7, J101.B7, U103.9 (USBDM), U_ESD101.3 (I/O2)
/USB_Power_Board/D_P: J101.A6, J101.B6, U103.8 (USBDP), U_ESD101.2 (I/O1)
GND: C101.2, C102.2, C103.1, C104.2, C105.2, C106.1, C107.2, C108.1, C109.2, C110.2, C112.1, C113.1, C114.2, C115.2, C116.2, D101.1 (K), D102.1 (K), J101.25 (SHIELD), J101.26 (SHIELD), J101.27 (SHIELD), J101.28 (SHIELD), J101.A1, J101.A12, J101.B1, J101.B12, R_CC101.2, R_CC102.2, U101.2 (GND), U102.1 (GND), U103.3 (GND), U103.13 (GND), U103.21 (GND), U104.4 (GND), U_ESD101.1 (GND); also elsewhere on the board
LED: R102.2; also elsewhere on the board
unnamed: D101.2 (A), R101.2
unnamed: D102.2 (A), R102.1
unnamed: F101.1, J101.A4, J101.A9, J101.B4, J101.B9
unnamed: J101.A5, R_CC102.1
unnamed: J101.B5, R_CC101.1
unnamed: C109.1, U103.10 (3V3OUT)
unnamed: R101.1, U103.15 (CBUS0)
unnamed: C111.1, U104.5 (C_{FLY+})
unnamed: C111.2, U104.3 (C_{FLY-})
unnamed: C112.2, L102.1, U104.1 (OUT)
UART_RX: U103.1 (RXD); also elsewhere on the board
UART_TX: U103.17 (TXD); also elsewhere on the board
−5V_A: C113.2, C114.1, L102.2; also elsewhere on the board

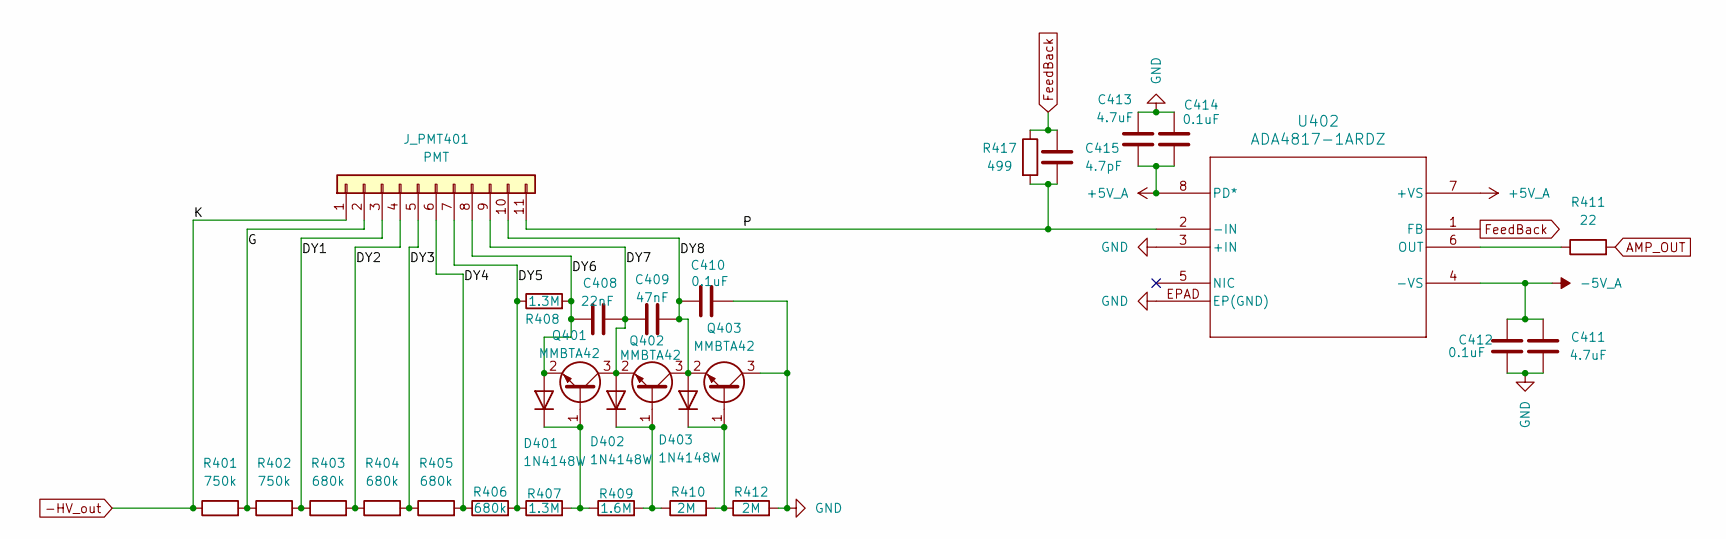
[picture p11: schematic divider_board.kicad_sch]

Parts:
C408: 22nF; C_1210_3225Metric_Pad1.33x2.70mm_HandSolder
C409: 47nF; C_1812_4532Metric_Pad1.57x3.40mm_HandSolder
C410: 0.1uF; C_1812_4532Metric_Pad1.57x3.40mm_HandSolder
C411, C413: 4.7uF; C_0805_2012Metric_Pad1.18x1.45mm_HandSolder
C412, C414: 0.1uF; C_0603_1608Metric_Pad1.08x0.95mm_HandSolder
C415: 4.7pF; C_0402_1005Metric_Pad0.74x0.62mm_HandSolder
D401, D402, D403: 1N4148W; D_SOD-123
J_PMT401: PMT; J_PMT401_R1307-01
Q401, Q402, Q403: MMBTA42; SOT-23
R401, R402: 750k; R_1206_3216Metric_Pad1.30x1.75mm_HandSolder
R403, R404, R405, R406: 680k; R_1206_3216Metric_Pad1.30x1.75mm_HandSolder
R407, R408: 1.3M; R_1206_3216Metric_Pad1.30x1.75mm_HandSolder
R409: 1.6M; R_1206_3216Metric_Pad1.30x1.75mm_HandSolder
R410, R412: 2M; R_1206_3216Metric_Pad1.30x1.75mm_HandSolder
R411: 22; R_0402_1005Metric_Pad0.72x0.64mm_HandSolder
R417: 499; R_0603_1608Metric_Pad0.98x0.95mm_HandSolder
U402: ADA4817-1ARDZ; RD_8_1_ADI-M

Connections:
+5V_A: C413.1, C414.1, U402.7 (+VS), U402.8 (PD*); also elsewhere on the board
/Divider_Board/DY1: J_PMT401.3, R402.2, R403.1
/Divider_Board/DY2: J_PMT401.4, R403.2, R404.1
/Divider_Board/DY3: J_PMT401.5, R404.2, R405.1
/Divider_Board/DY4: J_PMT401.6, R405.2, R406.1
/Divider_Board/DY5: J_PMT401.7, R406.2, R407.1, R408.1
/Divider_Board/DY6: C408.1, D401.2 (A), J_PMT401.8, Q401.2 (E), R408.2
/Divider_Board/DY7: C408.2, C409.1, D402.2 (A), J_PMT401.9, Q401.3 (C), Q402.2 (E)
/Divider_Board/DY8: C409.2, C410.1, D403.2 (A), J_PMT401.10, Q402.3 (C), Q403.2 (E)
/Divider_Board/G: J_PMT401.2, R401.2, R402.1
/Divider_Board/P: C415.1, J_PMT401.11, R417.2, U402.2 (-IN)
AMP_OUT: R411.2; also elsewhere on the board
FeedBack: C415.2, R417.1, U402.1 (FB)
GND: C410.2, C411.1, C412.1, C413.2, C414.2, Q403.3 (C), R412.2, U402.3 (+IN), U402.EPAD (EP(GND)); also elsewhere on the board
unnamed: D401.1 (K), Q401.1 (B), R407.2, R409.1
unnamed: D402.1 (K), Q402.1 (B), R409.2, R410.1
unnamed: D403.1 (K), Q403.1 (B), R410.2, R412.1
unnamed: R411.1, U402.6 (OUT)
−5V_A: C411.2, C412.2, U402.4 (-VS); also elsewhere on the board
−HV_out: J_PMT401.1, R401.1; also elsewhere on the board

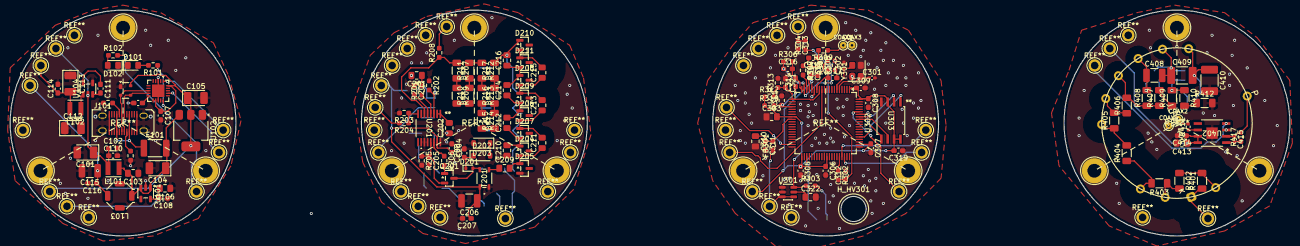
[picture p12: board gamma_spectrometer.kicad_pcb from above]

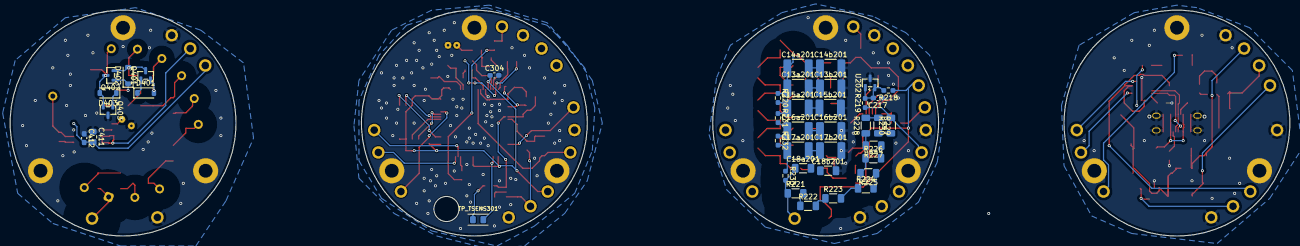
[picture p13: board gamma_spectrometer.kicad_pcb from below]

Board: 2 copper layers, 255.0 x 45.0 mm, 183 parts (40 on the bottom side), 115 nets.

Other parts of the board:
COAX1, COAX2, COAX3, COAX4: COAX_PIN_D0.5
H_HV301: HOLE_HV_WIRE_D5.0
TP_TSENS301: TP_TSENS_2x0805

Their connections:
AMP_OUT: COAX1.1, COAX2.1; also elsewhere on the board
GND: COAX3.1, COAX4.1; also elsewhere on the board
TSENS_IN: TP_TSENS301.2; also elsewhere on the board
TSENS_PWR: TP_TSENS301.1; also elsewhere on the board

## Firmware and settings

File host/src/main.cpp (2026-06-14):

// main.cpp — GUI-режим gammapult: диагностический пульт гамма-спектрометра.
// Win32 + DirectX 11 + Dear ImGui + ImPlot. Единый .exe без зависимостей.
// Раздвижные панели: связь, телеметрия, калибровка, живой спектр, консоль, самотест.

#include "imgui.h"
#include "imgui_impl_win32.h"
#include "imgui_impl_dx11.h"
#include "implot.h"

#include <d3d11.h>
#include <tchar.h>
#include <cstdio>
#include <cstring>
#include <cmath>
#include <vector>

#include "device.h"
#include "theme.h"
#include "host_app.h"

// --- DirectX 11 ---
static ID3D11Device*           g_pd3dDevice = nullptr;
static ID3D11DeviceContext*    g_pd3dDeviceContext = nullptr;
static IDXGISwapChain*         g_pSwapChain = nullptr;
static ID3D11RenderTargetView* g_mainRenderTargetView = nullptr;

static bool CreateDeviceD3D(HWND hWnd);
static void CleanupDeviceD3D();
static void CreateRenderTarget();
static void CleanupRenderTarget();
static LRESULT WINAPI WndProc(HWND, UINT, WPARAM, LPARAM);
extern IMGUI_IMPL_API LRESULT ImGui_ImplWin32_WndProcHandler(HWND, UINT, WPARAM, LPARAM);

// --- состояние приложения ---
static Device g_dev;
static bool   g_quit = false;
static int    g_port_sel = 0;
static bool   g_log_scale = true;
static char   g_cmd_buf[128] = "";
static bool   g_open_help = false;
static float  gLeftW = 300.0f, gRightW = 340.0f, gConnH = 276.0f, gConsoleH = 190.0f;
static float  gTeleH = 230.0f;

// калибровка энергий (канал → кэВ)
struct CalPoint { double energy = 0.0; double channel = 0.0; bool has_ch = false; };
struct Isotope  { const char* name; int n; double e[8]; };
static const Isotope ISOTOPES[] = {
    { "— нет —", 0, { 0 } },
    { "Am-241",  1, { 59.5 } },
    { "Cs-137",  1, { 661.7 } },
    { "Co-60",   2, { 1173.2, 1332.5 } },
    { "Lu-176",  3, { 88.0, 201.8, 306.8 } },
    { "Ra-226",  8, { 46.5, 186.2, 242.0, 295.2, 351.9, 609.3, 1120.3, 1764.5 } },
    { "Th-232",  5, { 238.6, 338.3, 583.2, 911.2, 2614.5 } },
};
static const int N_ISO = (int)(sizeof(ISOTOPES) / sizeof(ISOTOPES[0]));
static std::vector<CalPoint> g_cal;
static bool   g_calib_active = false;
static int    g_cal_isotope  = 0;
static bool   g_cal_fitted   = false;
static int    g_cal_order    = 2;       // степень полинома 1..4 (как PolynomialOrder в BecqMoni)
static bool   g_cal_valid    = false;   // прошла ли проверка монотонности (BecqMoni CheckCalibration)
static double g_cal_c[5]     = { 0, 0, 0, 0, 0 };   // c0..c4: E = Σ cᵢ·chⁱ (сырые каналы)
static double g_cal_maxres   = 0.0;
static bool   g_sel_active   = false;
static double g_sel_x0 = 0.0, g_sel_x1 = 0.0;
static int    g_view_lo = 0, g_view_hi = Device::CHANNELS;   // окно отображаемых каналов
static bool   g_view_apply = false;
static float  g_spec_x[Device::CHANNELS];
static float  g_spec_y[Device::CHANNELS];

// ================= помощники UI =================

static bool PrimaryButton(const char* label, const ImVec2& sz = ImVec2(0, 0))
{
    using namespace theme;
    ImGui::PushStyleColor(ImGuiCol_Button,        c_accent);
    ImGui::PushStyleColor(ImGuiCol_ButtonHovered, c_accent_hover);
    ImGui::PushStyleColor(ImGuiCol_ButtonActive,  c_accent_active);
    ImGui::PushStyleColor(ImGuiCol_Text,          c_white);
    bool r = ImGui::Button(label, sz);
    ImGui::PopStyleColor(4);
    return r;
}

static bool DangerButton(const char* label, const ImVec2& sz = ImVec2(0, 0))
{
    using namespace theme;
    ImGui::PushStyleColor(ImGuiCol_Button,        ImVec4(0, 0, 0, 0));
    ImGui::PushStyleColor(ImGuiCol_ButtonHovered, c_danger_bg);
    ImGui::PushStyleColor(ImGuiCol_ButtonActive,  c_danger_bg);
    ImGui::PushStyleColor(ImGuiCol_Text,          c_danger);
    ImGui::PushStyleColor(ImGuiCol_Border,        c_danger);
    bool r = ImGui::Button(label, sz);
    ImGui::PopStyleColor(5);
    return r;
}

static void StatusDot(const ImVec4& col)
{
    ImVec2 p = ImGui::GetCursorScreenPos();
    float  h = ImGui::GetTextLineHeight();
    float  r = 4.5f;
    ImGui::GetWindowDrawList()->AddCircleFilled(ImVec2(p.x + r + 1, p.y + h * 0.5f),
                                                r, theme::U32(col));
    ImGui::Dummy(ImVec2(r * 2 + 7, h));
    ImGui::SameLine();
}

static void Caption(const char* s)
{
    ImGui::PushStyleColor(ImGuiCol_Text, theme::c_text_dim);
    ImGui::TextUnformatted(s);
    ImGui::PopStyleColor();
}

static void PanelHeader(const char* title)
{
    ImGui::PushFont(theme::font_small);
    ImGui::PushStyleColor(ImGuiCol_Text, theme::c_text_dim);
    ImGui::TextUnformatted(title);
    ImGui::PopStyleColor();
    ImGui::PopFont();
    ImGui::Separator();
    ImGui::Spacing();
}

static bool BeginPanel(const char* id, ImVec2 pos, ImVec2 size)
{
    ImGui::SetNextWindowPos(pos);
    ImGui::SetNextWindowSize(size);
    ImGuiWindowFlags f = ImGuiWindowFlags_NoMove | ImGuiWindowFlags_NoResize |
                         ImGuiWindowFlags_NoCollapse | ImGuiWindowFlags_NoTitleBar |
                         ImGuiWindowFlags_NoBringToFrontOnFocus |
                         ImGuiWindowFlags_NoSavedSettings;
    return ImGui::Begin(id, nullptr, f);
}

static float clampf(float v, float lo, float hi) { return v < lo ? lo : (v > hi ? hi : v); }

// Раздвижной разделитель: тонкое окно поверх стыка панелей. Возвращает дельту
// перетаскивания (по X для вертикального, по Y для горизонтального).
static float Splitter(const char* id, ImVec2 pos, ImVec2 size, bool vertical)
{
    ImGui::SetNextWindowPos(pos);
    ImGui::SetNextWindowSize(size);
    ImGui::PushStyleVar(ImGuiStyleVar_WindowBorderSize, 0.0f);
    ImGui::PushStyleVar(ImGuiStyleVar_WindowPadding, ImVec2(0, 0));
    ImGuiWindowFlags f = ImGuiWindowFlags_NoTitleBar | ImGuiWindowFlags_NoResize |
                         ImGuiWindowFlags_NoMove | ImGuiWindowFlags_NoScrollbar |
                         ImGuiWindowFlags_NoSavedSettings | ImGuiWindowFlags_NoBackground |
                         ImGuiWindowFlags_NoBringToFrontOnFocus | ImGuiWindowFlags_NoNavFocus;
    ImGui::Begin(id, nullptr, f);
    ImGui::InvisibleButton("s", size);
    bool active = ImGui::IsItemActive();
    bool hovered = ImGui::IsItemHovered();
    if (active || hovered) {
        ImGui::SetMouseCursor(vertical ? ImGuiMouseCursor_ResizeEW : ImGuiMouseCursor_ResizeNS);
        ImU32 col = theme::U32(active ? theme::c_accent : theme::c_accent_line);
        ImGui::GetWindowDrawList()->AddRectFilled(pos, ImVec2(pos.x + size.x, pos.y + size.y), col);
    }
    float d = active ? (vertical ? ImGui::GetIO().MouseDelta.x : ImGui::GetIO().MouseDelta.y) : 0.0f;
    ImGui::End();
    ImGui::PopStyleVar(2);
    return d;
}

static ImVec4 StateColor()
{
    using namespace theme;
    switch (g_dev.state) {
    case Device::State::Disconnected: return c_text_dim;
    case Device::State::Connecting:   return c_accent;
    case Device::State::Connected:    return c_ok;
    case Device::State::Acquiring:    return c_ok;
    case Device::State::Error:        return c_danger;
    }
    return c_text_dim;
}

// Центр пика в диапазоне каналов [cx0..cx1]: вычитаем линейный фон по краям,
// берём взвешенный центроид → суб-канальный центр.
static double FindCentroid(double cx0, double cx1)
{
    int a = (int)floor(cx0 < cx1 ? cx0 : cx1);
    int b = (int)ceil (cx0 < cx1 ? cx1 : cx0);
    if (a < 0) a = 0;
    if (b > Device::CHANNELS - 1) b = Device::CHANNELS - 1;
    if (b <= a) return (double)a;
    double bg0 = (double)g_dev.spectrum[a], bg1 = (double)g_dev.spectrum[b];
    double num = 0, den = 0;
    for (int i = a; i <= b; i++) {
        double bg = bg0 + (bg1 - bg0) * (double)(i - a) / (double)(b - a);
        double w = (double)g_dev.spectrum[i] - bg;
        if (w < 0) w = 0;
        num += (double)i * w; den += w;
    }
    return den > 0 ? num / den : (double)(a + b) / 2.0;
}

// Проверка валидности (порт BecqMoni CheckCalibration): энергия должна монотонно
// возрастать по каналам 0..N и лежать в пределах [-1000, 100000] кэВ.
static bool CheckCalibration()
{
    double prev = -1.0e18;
    for (int ch = 0; ch <= Device::CHANNELS; ch++) {
        double d = (double)ch;
        double e = g_cal_c[0] + d * (g_cal_c[1] + d * (g_cal_c[2] + d * (g_cal_c[3] + d * g_cal_c[4])));
        if (e <= -1000.0 || e >= 100000.0) return false;
        if (ch > 0 && e < prev) return false;
        prev = e;
    }
    return true;
}

// МНК-фит полинома выбранной степени E(ch)=Σcᵢ·chⁱ. Фитим в нормированной
// переменной xn=ch/CHANNELS (обусловленность), затем cᵢ = aᵢ / CHANNELSⁱ.
static void FitCalibration()
{
    double X[16], Y[16]; int n = 0;
    for (auto& p : g_cal)
        if (p.has_ch && p.energy > 0 && n < 16) { X[n] = p.channel; Y[n] = p.energy; n++; }
    g_cal_fitted = false;
    if (n < 2) return;

    int deg = g_cal_order; if (deg > n - 1) deg = n - 1; if (deg < 1) deg = 1;
    int m = deg + 1;
    const double S = (double)Device::CHANNELS;
    double A[5][6];
    for (int r = 0; r < m; r++) { for (int c = 0; c <= m; c++) A[r][c] = 0; }
    for (int k = 0; k < n; k++) {
        double xn = X[k] / S, pw[5]; pw[0] = 1;
        for (int j = 1; j < m; j++) pw[j] = pw[j - 1] * xn;
        for (int r = 0; r < m; r++) {
            for (int c = 0; c < m; c++) A[r][c] += pw[r] * pw[c];
            A[r][m] += pw[r] * Y[k];
        }
    }
    for (int col = 0; col < m; col++) {                 // Гаусс с выбором ведущего
        int piv = col;
        for (int r = col + 1; r < m; r++) if (fabs(A[r][col]) > fabs(A[piv][col])) piv = r;
        for (int c = 0; c <= m; c++) { double t = A[col][c]; A[col][c] = A[piv][c]; A[piv][c] = t; }
        if (fabs(A[col][col]) < 1e-12) return;
        for (int r = 0; r < m; r++) if (r != col) {
            double f = A[r][col] / A[col][col];
            for (int c = col; c <= m; c++) A[r][c] -= f * A[col][c];
        }
    }
    for (int i = 0; i < 5; i++) g_cal_c[i] = 0;
    for (int i = 0; i < m; i++) g_cal_c[i] = (A[i][m] / A[i][i]) / pow(S, (double)i);

    g_cal_maxres = 0;
    for (auto& p : g_cal) if (p.has_ch && p.energy > 0) {
        double ch = p.channel;
        double e = g_cal_c[0] + ch * (g_cal_c[1] + ch * (g_cal_c[2] + ch * (g_cal_c[3] + ch * g_cal_c[4])));
        double d = fabs(e - p.energy);
        if (d > g_cal_maxres) g_cal_maxres = d;
    }
    g_cal_fitted = true;
    g_cal_valid  = CheckCalibration();
}

// ================= панели =================

static void PanelConnection(ImVec2 pos, ImVec2 size)
{
    using namespace theme;
    BeginPanel("##conn", pos, size);
    PanelHeader("ПОДКЛЮЧЕНИЕ");

    bool busy = (g_dev.state != Device::State::Disconnected &&
                 g_dev.state != Device::State::Error);

    Caption("COM-порт");
    if (g_port_sel >= (int)g_dev.ports.size()) g_port_sel = 0;
    ImGui::BeginDisabled(busy);
    ImGui::SetNextItemWidth(-1);
    const char* prev = g_dev.ports.empty() ? "(нет портов)"
                                           : g_dev.ports[g_port_sel].c_str();
    if (ImGui::BeginCombo("##port", prev)) {
        for (int i = 0; i < (int)g_dev.ports.size(); i++)
            if (ImGui::Selectable(g_dev.ports[i].c_str(), i == g_port_sel))
                g_port_sel = i;
        ImGui::EndCombo();
    }
    ImGui::EndDisabled();

    Caption("Скорость");
    ImGui::SameLine();
    ImGui::PushFont(font_mono); ImGui::TextUnformatted("600000"); ImGui::PopFont();
    ImGui::SameLine(); Caption("бод · 8N1");
    ImGui::Spacing();

    if (g_dev.state == Device::State::Disconnected || g_dev.state == Device::State::Error) {
        if (PrimaryButton("Подключить", ImVec2(-1, 26)) && !g_dev.ports.empty())
            g_dev.connect(g_dev.ports[g_port_sel]);
        if (ImGui::Button("Обновить порты", ImVec2(-1, 0)))
            g_dev.refresh_ports();
    } else {
        if (!g_dev.acquiring) {
            if (PrimaryButton("Старт набора (-sta)", ImVec2(-1, 26)))
                g_dev.start();
        } else {
            if (DangerButton("Стоп набора (-sto)", ImVec2(-1, 26)))
                g_dev.stop();
        }
        if (ImGui::Button("Сброс спектра (-rst)", ImVec2(-1, 0)))
            g_dev.reset_spectrum();
        if (DangerButton("Отключить", ImVec2(-1, 0)))
            g_dev.disconnect();
    }

    ImGui::Separator();
    StatusDot(StateColor());
    ImGui::TextUnformatted(g_dev.status_text.c_str());
    ImGui::Separator();

    Caption("Серийник");
    ImGui::PushFont(font_mono);
    ImGui::PushStyleColor(ImGuiCol_Text, c_accent);
    ImGui::TextUnformatted(g_dev.serial.empty() ? "—" : g_dev.serial.c_str());
    ImGui::PopStyleColor(); ImGui::PopFont();

    Caption("Прошивка");
    ImGui::PushFont(font_mono);
    ImGui::PushStyleColor(ImGuiCol_Text, c_text_strong);
    ImGui::TextWrapped("%s", g_dev.fw_info.empty() ? "—" : g_dev.fw_info.c_str());
    ImGui::PopStyleColor(); ImGui::PopFont();

    ImGui::End();
}

static void PanelTelemetry(ImVec2 pos, ImVec2 size)
{
    using namespace theme;
    BeginPanel("##tele", pos, size);
    PanelHeader("СТАТУС / ТЕЛЕМЕТРИЯ");

    Caption("Время набора");
    char tb[16];
    uint32_t s = g_dev.elapsed_s;
    snprintf(tb, sizeof(tb), "%02u:%02u:%02u", s / 3600, (s / 60) % 60, s % 60);
    ImGui::PushFont(font_mono_time); ImGui::TextUnformatted(tb); ImGui::PopFont();
    ImGui::Spacing();

    Caption("Скорость счёта, cps");
    char cb[24]; snprintf(cb, sizeof(cb), "%u", g_dev.cps);
    ImGui::PushFont(font_mono_big);
    ImGui::PushStyleColor(ImGuiCol_Text, g_dev.acquiring ? c_accent : c_text_strong);
    ImGui::TextUnformatted(cb);
    ImGui::PopStyleColor(); ImGui::PopFont();
    ImGui::Spacing();

    Caption("Отбраковано"); ImGui::SameLine();
    char ib[24]; snprintf(ib, sizeof(ib), "%u", g_dev.invalid);
    ImGui::PushFont(font_mono);
    ImGui::PushStyleColor(ImGuiCol_Text, c_warn); ImGui::TextUnformatted(ib);
    ImGui::PopStyleColor(); ImGui::PopFont();

    Caption("Суммарный счёт"); ImGui::SameLine();
    char sb[32]; snprintf(sb, sizeof(sb), "%llu", (unsigned long long)g_dev.total());
    ImGui::PushFont(font_mono); ImGui::TextUnformatted(sb); ImGui::PopFont();

    ImGui::Spacing(); ImGui::Separator();
    if (g_dev.acquiring) {
        StatusDot(c_accent);
        ImGui::PushStyleColor(ImGuiCol_Text, c_accent);
        ImGui::TextUnformatted("ИДЁТ НАБОР");
        ImGui::PopStyleColor();
    } else {
        StatusDot(c_text_dim); Caption("Набор остановлен");
    }

    ImGui::Separator();
    Caption("Порог детектора, каналов:");
    ImGui::SetNextItemWidth(72);
    ImGui::InputInt("##thr", &g_dev.threshold_ch, 0, 0);
    ImGui::SameLine();
    if (ImGui::Button("Применить##thr")) {
        char c[24]; snprintf(c, sizeof(c), "-thr %d", g_dev.threshold_ch);
        g_dev.send_cmd(c);
    }
    ImGui::End();
}

static void PanelSpectrum(ImVec2 pos, ImVec2 size)
{
    using namespace theme;
    BeginPanel("##spec", pos, size);

    ImGui::PushFont(font_small);
    ImGui::PushStyleColor(ImGuiCol_Text, c_text_dim);
    ImGui::TextUnformatted("СПЕКТР");
    ImGui::PopStyleColor(); ImGui::PopFont();

    // сегмент Лин/Лог справа
    float rx = ImGui::GetWindowWidth() - 8 - 88;
    ImGui::SameLine(rx);
    auto seg = [&](const char* lbl, bool active) {
        if (active) {
            ImGui::PushStyleColor(ImGuiCol_Button, c_accent);
            ImGui::PushStyleColor(ImGuiCol_Text, c_white);
        }
        bool r = ImGui::Button(lbl, ImVec2(42, 0));
        if (active) ImGui::PopStyleColor(2);
        return r;
    };
    if (seg("Лин", !g_log_scale)) g_log_scale = false;
    ImGui::SameLine(0, 2);
    if (seg("Лог", g_log_scale)) g_log_scale = true;
    ImGui::Separator();

    char st[128];
    snprintf(st, sizeof(st), "Σ %llu    пик %d",
             (unsigned long long)g_dev.total(), g_dev.peak_channel());
    ImGui::PushFont(font_mono);
    ImGui::PushStyleColor(ImGuiCol_Text, c_text_dim);
    ImGui::TextUnformatted(st);
    ImGui::PopStyleColor(); ImGui::PopFont();

    for (int i = 0; i < Device::CHANNELS; i++) {
        g_spec_x[i] = (float)i;
        g_spec_y[i] = (float)g_dev.spectrum[i];
    }

    ImVec2 avail = ImGui::GetContentRegionAvail();
    // в режиме калибровки ЛКМ свободна под выделение (пан уводим на среднюю кнопку)
    ImPlot::GetInputMap().Pan = g_calib_active ? ImGuiMouseButton_Middle : ImGuiMouseButton_Left;
    if (ImPlot::BeginPlot("##plot", avail,
                          ImPlotFlags_NoLegend | ImPlotFlags_NoMenus | ImPlotFlags_NoTitle)) {
        // X — навигация мышью (колесо/перетаскивание). Y — авто-подгон под данные,
        // поэтому спектр виден и в линейном, и в лог-масштабе.
        // Shift: колесо масштабирует Y (X на это время фиксируется).
        bool shift = ImGui::GetIO().KeyShift;
        ImPlot::SetupAxis(ImAxis_X1, "канал", shift ? ImPlotAxisFlags_Lock : ImPlotAxisFlags_None);
        ImPlot::SetupAxis(ImAxis_Y1, "счёт",  shift ? ImPlotAxisFlags_None : ImPlotAxisFlags_AutoFit);
        if (g_log_scale) ImPlot::SetupAxisScale(ImAxis_Y1, ImPlotScale_Log10);
        // нельзя уехать за пределы данных: X в [0..8192], Y не ниже нуля
        ImPlot::SetupAxisLimitsConstraints(ImAxis_X1, 0.0, (double)Device::CHANNELS);
        ImPlot::SetupAxisLimitsConstraints(ImAxis_Y1, g_log_scale ? 0.1 : 0.0, 1.0e12);
        if (g_view_apply) {            // одноразово выставить окно каналов (дальше можно зумить колесом)
            int lo = g_view_lo < 0 ? 0 : g_view_lo;
            int hi = g_view_hi > Device::CHANNELS ? Device::CHANNELS : g_view_hi;
            if (hi <= lo) hi = lo + 1;
            ImPlot::SetupAxisLimits(ImAxis_X1, lo, hi, ImPlotCond_Always);
            g_view_apply = false;
        } else {
            ImPlot::SetupAxisLimits(ImAxis_X1, 0, Device::CHANNELS, ImPlotCond_Once);
        }
        ImPlot::PushStyleColor(ImPlotCol_Line, c_trace);
        ImPlot::PlotLine("спектр", g_spec_x, g_spec_y, Device::CHANNELS);
        ImPlot::PopStyleColor();

        if (g_calib_active) {
            ImPlotRect lim = ImPlot::GetPlotLimits();
            if (ImPlot::IsPlotHovered() && ImGui::IsMouseClicked(ImGuiMouseButton_Left)) {
                g_sel_active = true;
                g_sel_x0 = g_sel_x1 = ImPlot::GetPlotMousePos().x;
            }
            if (g_sel_active && ImGui::IsMouseDown(ImGuiMouseButton_Left))
                g_sel_x1 = ImPlot::GetPlotMousePos().x;
            if (g_sel_active && ImGui::IsMouseReleased(ImGuiMouseButton_Left)) {
                g_sel_active = false;
                if (fabs(g_sel_x1 - g_sel_x0) >= 2.0) {
                    double c = FindCentroid(g_sel_x0, g_sel_x1);
                    int tgt = -1;
                    for (int i = 0; i < (int)g_cal.size(); i++)
                        if (!g_cal[i].has_ch) { tgt = i; break; }
                    if (tgt < 0) { g_cal.push_back(CalPoint{}); tgt = (int)g_cal.size() - 1; }
                    g_cal[tgt].channel = c; g_cal[tgt].has_ch = true;
                    g_cal_fitted = false;
                }
            }
            ImPlot::PushPlotClipRect();
            ImDrawList* dl = ImPlot::GetPlotDrawList();
            if (g_sel_active) {
                double a = g_sel_x0 < g_sel_x1 ? g_sel_x0 : g_sel_x1;
                double b = g_sel_x0 < g_sel_x1 ? g_sel_x1 : g_sel_x0;
                ImVec2 p0 = ImPlot::PlotToPixels(a, lim.Y.Max);
                ImVec2 p1 = ImPlot::PlotToPixels(b, lim.Y.Min);
                dl->AddRectFilled(p0, p1, U32(c_accent_sel));
            }
            for (size_t i = 0; i < g_cal.size(); i++) if (g_cal[i].has_ch) {
                ImVec2 t   = ImPlot::PlotToPixels(g_cal[i].channel, lim.Y.Max);
                ImVec2 btm = ImPlot::PlotToPixels(g_cal[i].channel, lim.Y.Min);
                dl->AddLine(t, btm, U32(c_cursor), 1.0f);
            }
            ImPlot::PopPlotClipRect();
        }
        ImPlot::EndPlot();
    }
    ImGui::End();
}

static void PanelConsole(ImVec2 pos, ImVec2 size)
{
    using namespace theme;
    BeginPanel("##con", pos, size);
    PanelHeader("КОНСОЛЬ · shproto");

    const char* chips[] = { "-sta", "-sto", "-rst", "-inf", "-cal",
                            "-tst spec", "-tst ra", "-tst off", "-tst enc" };
    ImGui::PushFont(font_small);
    for (int i = 0; i < (int)(sizeof(chips) / sizeof(chips[0])); i++) {
        if (i) ImGui::SameLine();
        if (ImGui::SmallButton(chips[i])) g_dev.send_cmd(chips[i]);
    }
    ImGui::PopFont();

    ImGui::BeginChild("log", ImVec2(0, -30), true);
    ImGui::PushFont(font_mono);
    for (const auto& l : g_dev.log) {
        ImVec4 col; const char* pre;
        switch (l.dir) {
        case 1:  col = c_accent;   pre = "-> "; break;
        case 2:  col = c_ok;       pre = "<- "; break;
        case 3:  col = c_danger;   pre = "!! "; break;
        default: col = c_text_dim; pre = ".. "; break;
        }
        ImGui::PushStyleColor(ImGuiCol_Text, col);
        ImGui::TextWrapped("%s%s", pre, l.text.c_str());
        ImGui::PopStyleColor();
    }
    if (ImGui::GetScrollY() >= ImGui::GetScrollMaxY() - 4.0f)
        ImGui::SetScrollHereY(1.0f);
    ImGui::PopFont();
    ImGui::EndChild();

    ImGui::SetNextItemWidth(-78);
    bool enter = ImGui::InputText("##cmd", g_cmd_buf, sizeof(g_cmd_buf),
                                  ImGuiInputTextFlags_EnterReturnsTrue);
    ImGui::SameLine();
    if ((PrimaryButton("Отправить") || enter) && g_cmd_buf[0]) {
        g_dev.send_cmd(g_cmd_buf);
        g_cmd_buf[0] = 0;
    }
    ImGui::End();
}
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

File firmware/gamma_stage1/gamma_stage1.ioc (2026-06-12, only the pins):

Mcu.UserName=STM32G474RETx
PA13.GPIO_Label=T_SWDIO
PA13.Signal=SYS_JTMS-SWDIO
PA14.GPIO_Label=T_SWCLK
PA14.Signal=SYS_JTCK-SWCLK
PA2.Signal=USART2_TX
PA3.Signal=USART2_RX
PA5.Signal=GPIO_Output
PB3.GPIO_Label=T_SWO
PB3.Signal=SYS_JTDO-SWO
PC13.Signal=GPXTI13
PC14-OSC32_IN.GPIO_Label=RCC_OSC32_IN
PC14-OSC32_IN.Signal=RCC_OSC32_IN
PC15-OSC32_OUT.GPIO_Label=RCC_OSC32_OUT
PC15-OSC32_OUT.Signal=RCC_OSC32_OUT
PF0-OSC_IN.GPIO_Label=RCC_OSC_IN
PF0-OSC_IN.Signal=RCC_OSC_IN
PF1-OSC_OUT.GPIO_Label=RCC_OSC_OUT
PF1-OSC_OUT.Signal=RCC_OSC_OUT

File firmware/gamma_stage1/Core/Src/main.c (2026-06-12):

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
/* Includes ------------------------------------------------------------------*/
#include "main.h"

/* USER CODE BEGIN Includes */
#include "app.h"
void stage2_init(void);   /* stage2_hw.c: DAC→ADC→DSP тракт */
/* USER CODE END Includes */


COM_InitTypeDef BspCOMInit;

/* USER CODE BEGIN PV */
#define UART_RX_RING_SIZE 256
static uint8_t  uart_rx_ring[UART_RX_RING_SIZE];
static uint32_t uart_rx_tail = 0;

/* Имя hdma_usart2_rx обязано совпадать со ссылкой в DMA1_Channel1_IRQHandler
 * (stm32g4xx_it.c). Фактически канал обслуживает LPUART1_RX — VCP платы. */
DMA_HandleTypeDef hdma_usart2_rx;
/* USER CODE END PV */

void SystemClock_Config(void);
static void MX_GPIO_Init(void);
static void MX_DMA_Init(void);
/* USER CODE BEGIN 0 */

/* ---- порты для app.c (см. firmware/core/app.h) ---- */

void app_port_uart_send(const uint8_t *data, size_t n)
{
    HAL_UART_Transmit(&hcom_uart[COM1], (uint8_t *)data, (uint16_t)n, 2000);
}

uint32_t app_port_millis(void)
{
    return HAL_GetTick();
}

float app_port_temperature_c(void)
{
    return 25.0f;   /* этап 1: заглушка; на боевой плате — Pt1000 через ADC4 */
}

/* ---- VCP: перенастройка на 600000 бод + кольцевой DMA-приём ---- */

static void vcp_init_600000(void)
{
    /* BSP_COM_Init уже поднял LPUART1 (PA2/PA3) на 115200 — меняем только скорость */
    hcom_uart[COM1].Init.BaudRate = 600000;
    if (HAL_UART_Init(&hcom_uart[COM1]) != HAL_OK)
        Error_Handler();

    hdma_usart2_rx.Instance                 = DMA1_Channel1;
    hdma_usart2_rx.Init.Request             = DMA_REQUEST_LPUART1_RX;
    hdma_usart2_rx.Init.Direction           = DMA_PERIPH_TO_MEMORY;
    hdma_usart2_rx.Init.PeriphInc           = DMA_PINC_DISABLE;
    hdma_usart2_rx.Init.MemInc              = DMA_MINC_ENABLE;
    hdma_usart2_rx.Init.PeriphDataAlignment = DMA_PDATAALIGN_BYTE;
    hdma_usart2_rx.Init.MemDataAlignment    = DMA_MDATAALIGN_BYTE;
    hdma_usart2_rx.Init.Mode                = DMA_CIRCULAR;
    hdma_usart2_rx.Init.Priority            = DMA_PRIORITY_LOW;
    if (HAL_DMA_Init(&hdma_usart2_rx) != HAL_OK)
        Error_Handler();
    __HAL_LINKDMA(&hcom_uart[COM1], hdmarx, hdma_usart2_rx);

    HAL_UART_Receive_DMA(&hcom_uart[COM1], uart_rx_ring, UART_RX_RING_SIZE);
}

/* вычитка кольцевого DMA-буфера: отдать в app всё, что накапало */
static void uart_rx_poll(void)
{
    uint32_t head = UART_RX_RING_SIZE - __HAL_DMA_GET_COUNTER(&hdma_usart2_rx);
    while (uart_rx_tail != head) {
        uint32_t chunk_end = (head > uart_rx_tail) ? head : UART_RX_RING_SIZE;
        app_rx_feed(&uart_rx_ring[uart_rx_tail], chunk_end - uart_rx_tail);
        uart_rx_tail = (chunk_end == UART_RX_RING_SIZE) ? 0u : chunk_end;
        head = UART_RX_RING_SIZE - __HAL_DMA_GET_COUNTER(&hdma_usart2_rx);
    }
}
/* USER CODE END 0 */

/**
  * @brief  The application entry point.
  * @retval int
  */
int main(void)
{

  /* MCU Configuration--------------------------------------------------------*/

  /* Reset of all peripherals, Initializes the Flash interface and the Systick. */
  HAL_Init();

  /* Configure the system clock */
  SystemClock_Config();

  /* Initialize all configured peripherals */
  MX_GPIO_Init();
  MX_DMA_Init();
  /* Initialize led */
  BSP_LED_Init(LED_GREEN);

  /* Initialize USER push-button, will be used to trigger an interrupt each time it's pressed.*/
  BSP_PB_Init(BUTTON_USER, BUTTON_MODE_EXTI);

  /* Initialize COM1 port (115200, 8 bits (7-bit data + 1 stop bit), no parity */
  BspCOMInit.BaudRate   = 115200;
  BspCOMInit.WordLength = COM_WORDLENGTH_8B;
  BspCOMInit.StopBits   = COM_STOPBITS_1;
  BspCOMInit.Parity     = COM_PARITY_NONE;
  BspCOMInit.HwFlowCtl  = COM_HWCONTROL_NONE;
  if (BSP_COM_Init(COM1, &BspCOMInit) != BSP_ERROR_NONE)
  {
    Error_Handler();
  }

  /* Infinite loop */
  /* USER CODE BEGIN WHILE */
  vcp_init_600000();   /* после BSP_COM_Init: 115200 → 600000 + DMA RX */
  stage2_init();       /* DAC→(перемычка A2-A0)→ADC→DSP */
  app_init();
  while (1)
  {

    /* USER CODE END WHILE */

    /* USER CODE BEGIN 3 */
    uart_rx_poll();
    app_poll();
  }
  /* USER CODE END 3 */
}

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
/* USER CODE BEGIN 4 */
/* При ошибке линии (шум/обрыв) HAL останавливает DMA-приём — перезапускаем */
void HAL_UART_ErrorCallback(UART_HandleTypeDef *huart)
{
    if (huart == &hcom_uart[COM1]) {
        uart_rx_tail = 0;
        HAL_UART_Receive_DMA(&hcom_uart[COM1], uart_rx_ring, UART_RX_RING_SIZE);
    }
}
/* USER CODE END 4 */
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


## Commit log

2026-05-21 Initial commit: NaI(Tl) gamma spectrometer project
    - KiCad schematics for all 4 boards (USB/Power, HV, MCU, Divider)
    - LTspice simulations (AD8000, CR-RC2 shaper, noise)
    - Documentation and datasheets
    - BOM and footprint work in progress
    - Host software skeleton (shproto)
    [divider_board.kicad_sch, gamma_spectrometer.csv, gamma_spectrometer.kicad_pcb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]
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2026-05-22 Complete BOM: MPN and footprints for all components
    Session 5 (2026-05-23) - full BOM assignment finished.
    Components assigned (KiCad Symbol Fields + Footprints):
    - 81 capacitors / 17 unique MPN (Yageo, Murata, Vishay, Holy Stone)
    - 79 resistors / 28 unique MPN (Yageo RC/RT/RL/AC series)
    - 3 inductors (Bourns SRN3015 + SRU5028)
    - 2 LEDs (Foryard + Wurth 0805)
    - 1 PTC fuse (MF-MSMF050-2)
    - 1 ferrite bead (Murata BLM18EG121SN1D, 0603 - fixed from docs 0402)
    - All active ICs (STM32G474, MAX1847, AD8000, FT231XQ, etc.)
    Key design decisions:
    - Standard bypass: 100nF X7R 0603 (easier hand soldering vs 0402)
    - LED package 0805 (instead of 0402)
    - C115 consolidated with C206 on single MPN (GRM32ER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
    [divider_board.kicad_sch, hv_board.kicad_sch, mcu_board.kicad_sch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]
2026-06-10 Fix 2 critical schematic bugs found by full netlist audit
    Full audit of all 191 nets (sessions 7-8, 2026-06-10/11) against design docs.
    CRITICAL FIXES (schematic + netlist):
    1. UART was straight-through, not crossed: FTDI TXD tied to PA9 (both
    outputs), RXD to PA10 (both inputs) - no communication possible.
    ERC missed it (MCU pins are bidirectional). Now: PA9(TX)->UART_RX
    ->FTDI RXD, FTDI TXD->UART_TX->PA10(RX).
    2. PMT divider active buffers were dead: chain junctions were merged
    with dynodes DY6/7/8, so base resistors bridged base to own emitter
    (Vbe=0 forever, MMBTA42 never conducts). Now: dynode = emitter only;
    chain junction -> base resistor -> base; storage caps betwe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
    [divider_board.kicad_sch, mcu_board.kicad_sch]
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2026-06-10 firmware: avoid float printf in -inf reply (newlib-nano default)
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2026-06-12 firmware: stage 1 CubeIDE project - integrated, builds clean
    NUCLEO-G474RE project (gamma_stage1) with core modules integrated into
    USER CODE sections (survives CubeMX regeneration):
    - BSP COM1 (LPUART1, PA2/PA3 = ST-LINK VCP) re-inited 115200 -> 600000
    - Circular DMA RX on DMA1_Channel1 (DMA_REQUEST_LPUART1_RX); handle named
    hdma_usart2_rx to match the generated IRQ handler reference in it.c
    (leftover from an earlier USART2 config; declaration added in USER CODE EV)
    - UART error callback restarts DMA reception
    - Headless build via stm32cubeidec: 0 errors, 0 warnings (19 KB text)
    Setup pain points solved along the way (for the record):
    - ST package downloads blocked -> STM32Cube_FW_G4 V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
    [gamma_stage1.ioc, main.c]
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2026-06-12 stage 1 bring-up complete: board speaks shproto, fake spectrum flows
    Root cause of the flashing saga: bad USB cable (bulk transfers corrupted -
    flash ops and ST-Link FW upgrade failed while reads/single writes worked).
    Verified on hardware: -sta/-sto/-rst/-inf handshake, CRC both ways,
    500 cps synthetic spectrum, peaks at channels 101 and 1138 as designed.
2026-06-12 firmware: reset test generator timer on -sta (burst of stale counts)
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2026-06-12 firmware: status elapsed field is SECONDS, not milliseconds
    BecqMoni does TimeSpan.FromSeconds(ElapsedTime) - we were sending ms,
    so the acquisition timer ran 1000x fast. Spec note in session_context
    corrected (was discovered wrong on real hardware).
    [becqmoni_sim.py]
2026-06-12 stage 1 COMPLETE: first spectrum through the full stack
    Nucleo-G474RE -> shproto/VCP 600000 -> BecqMoni -> XML export.
    78 s acquisition, 502 cps, synthetic peaks at channels 101 and 1140
    exactly as designed. Timer now 1:1 after the seconds fix.
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2026-06-13 firmware: built-in self-test subsystem + hardened pulse detector
    Self-test (the test generator's true purpose per spec, adc_mcu_board 3.2):
    shproto commands usable from BecqMoni device command line:
    -tst off|spec|mono <amp> [t_us]|stat|enc
    -tst enc runs automatically: 5 amplitudes x 1000 events @ 1 kHz, reports
    centroid/sigma/FWHM per point + tract slope + max INL.
    First hardware ENC report:
    k=2.0048 ch/code, INL max=0.025%FS,
    FWHM @ Cs-equivalent (ch 1612) = 10.7 ch = 0.66% - electronics+DSP
    contribution is negligible vs 6.3% PMT statistics, as sim3 promised.
    Detector hardening (bugs found by porting dsp.c to Python and simulating
    the exact DAC staircase + noise offline - reproduc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
2026-06-13 session_context: quick-start block for context compaction recovery
    Also: R301 purchase URL fix in mcu_board schematic (user edit, was pending).
    [mcu_board.kicad_sch]
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2026-06-14 pcb: старт разводки USB/Power + план межплатных соединений
    Сессия 12 (обучение разводке с нуля, KiCad 9, все 4 платы в одном
    gamma_spectrometer.kicad_pcb):
    - USB/Power: стек 4 слоя, контур Ø45, импорт футпринтов, обвязка USB-C
    (D+/D- с via, VBUS, CC 5.1k), узлы FT231X(U103) и AMS1117(U102) с развязкой,
    полигон GND на всех слоях + сшивающие via, питание частично
    - решение по межплатке: цанговые гнёзда (сигнал/питание, footprint Ø2.5/сверло1.5)
    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
    [gamma_spectrometer.kicad_pcb]
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2026-06-15 sim: заморозка приёмочного стенда C2a (undershoot/запас VREF)
    Методология «проект под верный результат»: стенд заморожен, правится только DUT,
    пороги заданы ДО фикса, pass/fail выносит холодная ревью-сессия.
    - dut_shaper.cir — DUT (тракт шейпера amp_out→adc_in, дословно из sim2_shaper.cir)
    - c2a_bench.cir — эталон C2a (одиночный импульс), пороги T1≤2.445В / T2≤15% / T3≥50мВ
    на 2.614 и 3.5 МэВ; стимул worst-case (τ=230нс, AD8000×−15)
    - c2_README.md — методоло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
2026-06-15 sim: заморозка приёмочного стенда C2b (рейт / пара импульсов)
    c2b_bench.cir — эталон рейт-части C2: 2 импульса 2.614 МэВ, свип интервала 2..33 мкс,
    амплитуда 2-го от локальной базовой (покадровый ComputeBaseline).
    Пороги: T5 ошибка ≤1% (гейт dt>=4мкс; 2..3мкс=pile-up/M1 информативно),
    T1-rate V_max≤2.445В на всём свипе.
    Базовая точка «до фикса»: T1-rate FAIL везде (2.51..2.62В); T5 FAIL на 4мкс (2.82%).
    README дополнен таблицей C2b. .raw/.log в .gitignore.
    Co-Authored-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
2026-06-15 review: triage round2 + doc-гигиена (механизм undershoot, FWHM/rise)
    TRIAGE_round2.md — ответ по вердиктам: FIXED закрыты; N1(регресс +1.9%) задокумент.
    без DUT-правок (безвредна, погоня=scope creep); N2 — спека R_pz в схему пользователю;
    C1 — следующий (свой замороженный стенд); M1/M3 firmware этап3; M2/M4/M5/M6 отложены;
    N3 (T2 мягкий) — отдельной правкой стенда.
    doc-гигиена (honest, к измеренному round2):
    - adc_mcu §3.3: механизм undershoot = RC удваивает CR (AC-связи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
2026-06-15 pcb: схема MCU + BOM — R314 (R_pz 10k) добавлен пользователем (источник нетлиста)
    Согласует репо с уже закоммиченным нетлистом (фикс C2). Схему правил пользователь.
    [gamma_spectrometer.csv, mcu_board.kicad_sch]
2026-06-15 pcb: BOM перевыпущен — R314 (R_pz 10k) включён; N2 закрыт
    BOM gamma_spectrometer.csv: строка 10k теперь содержит R314 (Qty 10→11,
    MPN RC0603FR-0710KL). Фикс C2 интегрирован полностью: схема + нетлист + BOM.
    TRIAGE_round2: N2 отмечен завершённым (ждёт подтверждения round3).
    [gamma_spectrometer.csv]
2026-06-15 sim: заморозка приёмочного стенда C1 (просадка усиления делителя)
    dut_divider.cir — DUT делителя R1307 (R401-414 + буферы Q401-403), топология
    сверена с нетлистом. c1_bench.cir — эталон: HV -1500В + динодные токи (k=0/1,
    worst-case 30кимп/с@2.6МэВ). c1_check.py — усиление Π(зазор)^0.7 + T_C1 pass/fail.
    Базовая точка «до фикса» (воспроизводит ревью): сдвиг усиления -4.71%,
    пер-зазорные -0.84..-0.94% → T_C1(<=1%) FAIL. Порог T_C1=1% утверждён до фикса.
    .raw/.log в .gitigno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
2026-06-15 pcb: интеграция фикса C1 — Q403→GND, R414 убран, R412→1M + проверка
    Пользователь интегрировал C1 в divider_board: коллектор Q403 на GND, R414 удалён,
    R412 499k→1M (слияние R412+R414, узел midP исключён). Проверено по нетлисту:
    R412=1M cd8↔GND, R414 отсутствует, Q403.C→GND — верно.
    DUT (dut_divider.cir) обновлён под as-built топологию; перемерено на замороженном
    стенде: сдвиг усиления -0.144%, T_C1 PASS (как и предложенный фикс — слияние эквивалентно).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
    [divider_board.kicad_sch]
2026-06-15 pcb: BOM перегенерён под C1 — R414 убран, R412→1M; C1 закрыт в железе
    BOM: R414 удалён, R412 теперь 1M (строка R410,R412, MPN RC1206FR-071ML, 1206).
    R314 (C2) на месте. C1 интегрирован полностью: схема + нетлист + BOM.
    TRIAGE_round2: C1 отмечен закрытым (ждёт подтверждения round3).
    [gamma_spectrometer.csv]
2026-06-15 review: triage round3 — синхронизация divider doc (D1) + директивы R1/R2
    Round3 признал C1/C2 FIXED+интегрированными (независимо подтверждено), N2 закрыт.
    Новые находки — только доки/layout, схему не трогал:
    - D1: divider_board.md синхронизирован с фактом (R412=1М, R414 убран, mid_P/Q403.C→GND,
    таблица напряжений/bypass/стоимость)
    - R2: новое правило #10 в cheatsheet (звёздная земля под Q403.C — отдельно от сигнала анода)
    + ⚠ в divider_board.md
    - R1: watch-замет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
2026-06-16 pcb(usb): односторонний монтаж + стойки M2.5 + своп ESD D+/D−
    - FT231X (U103) + C107/C109 перенесены на верхний слой → на B.Cu
    компонентов 0, монтаж односторонний (проще/дешевле в сборке).
    - U_ESD101: D+/D− переставлены на I/O1/I/O2 (пины симметричны по
    даташиту PRTR5V0U2X) ради компоновки; идентичность линий сохранена
    (D+ →USBDP, D− →USBDM). Нетлист переэкспортирован.
    - Стойки M2.5 (STANDOFF_x3_TRIANGLE) в центр (100,100), все 3 пэда на GND.
    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
    [gamma_spectrometer.kicad_pcb]
2026-06-16 pcb(usb): GND-сшивка вианами + фикс C106/U101 + ESD VCC — DRC чист
    - Земля сшита вианами F.Cu/In1.Cu/B.Cu (виасы у U103, R_CC101, C109);
    GND-полигон собран в единый, островов нет.
    - Устранено наложение courtyard C106 ↔ U101.
    - U_ESD101 пин 4 (+3.3V_D) подключён.
    - DRC (headless kicad-cli): USB-локальных неподключённых 0, электрических
    нарушений 0. Остаётся косметика silk (44) и кросс-плата (ждёт межплатных пинов).
    [gamma_spectrometer.kicad_pcb]
2026-06-17 pcb: разводка HV + GND-полигоны + межплатная шина (HV/USB)
    - HV-плата разведена (накопит. конденсаторы и монитор-делитель вынесены вниз),
    GND залит полигонами, паритет со схемой 0.
    - USB: добавлен GND-план на In2.Cu (второй внутренний слой), сшивка.
    - Межплатная шина цанг-пинов: по 13 пинов на HV и USB, выровнены на R20
    равным шагом 13° с разрывами под стойки (120°/240°); углы идентичны на
    обеих платах -> соосность ч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
    [gamma_spectrometer.kicad_pcb]
2026-06-17 pcb: расположение символов в схеме USB + дефолт пэда в проекте
    - usb_power_board.kicad_sch: перестановка позиций символов/проводов
    (электрических изменений нет — связи, номиналы, метки прежние).
    - .kicad_pro: дефолтный размер пэда -> сверло 1.5 / 2.5x2.5 (под цанг-пины).
    [usb_power_board.kicad_sch]
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2026-06-20 fix(divider): AD8000 ОС на −IN (была OUT↔FB, петля разомкнута) + правило #11
    Инженер нашёл на живой схеме: Rfb(R417)/Cfb(C415) стояли между OUTPUT(6) и
    FEEDBACK(1). У AD8000 пин FB внутри = выход (даташит «Low Distortion Pinout»),
    поэтому оба конца сидели на выходном узле → на Rfb 0 В, петля ОС разомкнута,
    −IN без обратной связи → ОУ в насыщении, усиления ×−15 нет.
    Исправлено (схема + нетлист): Rfb‖Cfb теперь между FB(1) и −IN(2); выход (6)
    = AMP_OUT (U.F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
    [divider_board.kicad_sch]
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2026-06-23 divider: активный делитель пересобран по Fig 5-15 + валидирован
    Буферная секция переделана по Hamamatsu PMT Handbook (Fig 5-15, стр.108):
    цепочка через диноды, транзисторы смещены током делителя, защитные диоды B-E.
    Проверено simulation/sim_div_final.cir (-1500В, MMBTA42+1N4148 модели):
    - смещение Q401-403: Ic ≈ 96 мкА (было 0.19 нА — изъян закрыт), ток делителя 195 мкА.
    - распределение: K-G/G-Dy1 146В, Dy1-Dy5 132В, Dy6-Dy7 157В, Dy7-Dy8 197В,
    Dy8-GND 198В (тейпер восст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
    [divider_board.kicad_sch]
2026-06-23 divider: вход на ADA4817 TIA + единая модель всей платы делителя
    Вход переведён с AD8000-инвертора на ADA4817-1ARDZ (U402) как TIA:
    - анод P напрямую на −IN (виртуальная земля), R415/R416 убраны;
    - Rf=R417=499, Cf=C415=4.7пФ между FB и −IN; +IN→AGND, PD→+5V_A, EPAD→AGND.
    Единая модель simulation/sim_divider_complete.cir (делитель −1500В + буферы +
    диоды + TIA, транзиент с импульсом ФЭУ) подтверждает весь тракт:
    - диноды смещены (DY6/7/8 = −552/−395/−198В), буферы ~96мкА,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
    [divider_board.kicad_sch]
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2026-08-07 fix: полярность тракта, опора REF35250, DRC по электрике в ноль
    ПОЛЯРНОСТЬ (главное). Анод ФЭУ забирает условный ток => выход TIA идёт
    вверх => импульс на АЦП положительный. В доках и прошивке была обратная
    конвенция, выросшая из sim2_shaper.cir, где источник тока анода развёрнут
    (`I_pmt 0 anode` вместо `I_pmt anode 0`); sim_divider_complete.cir всё это
    время делал верно — две деки противоречили друг другу.
    Последствия при ста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
    [gamma_spectrometer.kicad_pcb, mcu_board.kicad_sch]
2026-08-07 fix(drc): правила ВВ-зазоров глушили проверку целиком — исправлено
    НАЙДЕНО ПОЛЬЗОВАТЕЛЕМ. Блок из 12 «исключений» в .kicad_dru для деталей,
    соединяющих ВВ-узел с землёй (T201, C210, D205, C410, R412, C13b201..C18b201,
    Q403), был написан как `(constraint clearance (min 0mm))` с условием
    `insideCourtyard('<ref>')`. Это не освобождает частный случай, а перебивает
    остальные правила и ОБНУЛЯЕТ проверку зазора глобально.
    Бисекция:
    49 ВВ-правил, бе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
    [gamma_spectrometer.kicad_pcb]
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2026-09-19 docs+sim: ревью-критик, расчёт C320/связей, модель земли МК, SWD проводами
    - review/REVIEW_critic_2026-09-15.md — независимый аудит (1 крит., 6 серьёзных);
    1.1 перепроверена по нетлисту.
    - simulation/fix_c320/ — варианты исправления 1.1/1.3: LTspice (30 мс) +
    Монте-Карло через настоящий firmware/core/dsp.c (DLL). Итог: V2 (без C320,
    C317/C314 = 1 мкФ); попутно: ЦАП PA4 режет усиление до ×0.887, фит по
    5 точкам на боевом импульсе даёт σ ≈ 3 %.
    - simulation/ground_mcu/ —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
    [run_spice.py]
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2026-09-20 hv: пульсации, устойчивость петли MAX1847 и наводка на FB (simulation/hv_loop)
    Переключательная модель платы ВВ в LTspice + матрица паразитных ёмкостей платы
    из FastCap по .kicad_pcb.
    Исправления в документации:
    - умножитель на 4 ступени, а не на 8: BAV23S = один диод (вывод 3 не подключён);
    отсюда размах на вторичке 310…385 В и упор флайбэк-полки в снаббер выше ~1300 В
    (КПД 83 % при 1200 В против 61 % при 1500 В);
    - RC-фильтр 3×100 кОм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
2026-09-29 docs(fab): состояние после переразмера виа
    Пользователь переразмерил виа и перезалил плату. Прогон kicad-cli drc:
    223 из 225 виа теперь 0.80/0.30, поясок 0.250 мм — норму ПС-Электро проходят;
    лишнее виа вне контуров удалено; замыкание SPI_MISO/SPI_MOSI, появившееся от
    роста пада, исправлено.
    Предсказание подтвердилось: все 80 нарушений с участием зоны сняла перезаливка,
    осталось ровно 56 -> 54 «дорожка/пад против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
2026-10-02 fix(bom): C209 — конденсатор снаббера 100 В вместо 50
    В BOM стоял CC0603KRX7R9BB103 (код 9BB = 50 В), а узел снаббера сидит на
    35.7 В с пиками 43-45 В. Заказан CC0603KRX7R0BB103 — та же серия Yageo,
    код 0BB = 100 В, корпус 0603, X7R, +-10%. При 36 В смещения X7R 0603 на
    100 В теряет ~20% ёмкости вместо >50% у 50-вольтового, то есть снаббер
    остаётся близко к расчётным 10 нФ.
    Заодно исправлена ошибка в CLAUDE.md: там было написано «ставить 100 В
    0805», тогда как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
2026-10-30 fw/docs: платы и REF35250 получены — внешняя опора АЦП по умолчанию
    - board_vref: по умолчанию REF35250 (U301), VREFBUF выключен и в HiZ;
    -DBOARD_VREF_INTERNAL — плата без U301; старый -DBOARD_VREF_EXTERNAL даёт #error
    - статусы RU/EN, CLAUDE.md, session_context, stock: платы и все компоненты на руках
2026-10-30 usb: сборка первого экземпляра — земля U104 без виа, исправлено в плате
    - 🔴 ошибка разводки: пад 4 (GND) TPS60400 U104 на островке F.Cu без виа —
    насос без земли, −5V_A = +2.3 В. На собранной плате — перемычка на GND C113.
    В .kicad_pcb: GND-виа у пада 4, C102 к входу U104, L102 сдвинут,
    дорожка −5V_A восстановлена. DRC: «не соединено» 25, все межплатные.
    gerbers.zip не перевыгружен (по нему сделаны платы)
    - usb_power_board_schematic §11: дорабо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
2026-11-03 mcu: стек собран целиком, тракт исправен; Pt1000 без земли — ошибка схемы
    - прошивка запуска: OPAMP1/2/3 + печать напряжений аналоговых узлов раз в 5 с
    - замеры стека без ФЭУ: база АЦП 394 мВ, OPAMP1 = 1.5·V_A (выход TIA ≈ 0),
    ноль HV_MONITOR 2.460 В, VREF+ 2.508 В
    - у TP_TSENS301 нет GND: TSENS_PWR и TSENS_IN одиночные цепи; как паять на v1
    и пункт в ревизию; R303 подтянут к VREF, а не к +3.3 В (дока исправлена)
    Claude-Ses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
2026-11-05 fw: исправления — ВВ: выдержка "over" от конца рампы, счётчики без переполнения
    - Защита "over" взводится через 30 с от конца рампы (рампа дошла до уставки),
    а не от команды; плюс прежние условия — выход устоялся и усреднённый монитор
    не падает (наклон ≥ 0).
    - Выдержки (HOLD и 30 с) — насыщающийся счётчик Σdt вместо now − t0:
    переполнение millis через 49.7 сут их не трогает (поля changed_ms,
    at_target_ms, over_armed убр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
2026-11-05 fw: исправления — детектор: порог и ширина на лету, авто-порог, бюджет, запись окон
    - det_set_thr / det_set_width без сброса базы, σ и статистики; det_thr,
    det_thr_measuring.
    - Авто-порог (cfg.thr = 0 или det_set_thr(d, 0), в настройках thr_codes = 0):
    σ по ближайшим DET_BASE_N спокойным отсчётам, порог round(5σ) в 3…1000;
    замер повторяется, пока порог не перестанет меняться (≤ 4 раз) — при σ
    много больше прежнего порога первый замер заниже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
2026-11-05 fw: исправления — настройки x8, флеш "defaults", -defaults при ВВ, термокомпенсация, замыкание Pt1000
    - settings_t: reserved[5] перед crc32, sizeof = 1000 (кратен 8 — запись
    двойными словами), проверка при сборке в settings.c и тест.
    - proto_flash_status: состояние "defaults" (во флеш пусто/битые настройки,
    работаем на умолчаниях) — proto_flash_defaults(), сбрасывается первой
    удачной записью.
    - -defaults при включённом ВВ (port->hv_on) — "-err hv_on", ничего не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
2026-11-05 fw: исправления — сборка: main связывает весь core, бюджет ОЗУ, CCM, syscalls
    - main.c вызывает весь core (settings, proto с портом, hv_ctl, temp,
    detector с эмиттером в spectrum, авто-порог по -sta, -osc через
    det_set_capture) на заглушках железа: штатная сборка проверяет линковку,
    CCM и ОЗУ. Резервы драйверов: DMA АЦП 32 КБ (в ОЗУ — CCM недоступна DMA),
    кольцо UART 8 КБ; стек 4 КБ и куча 2 КБ (strtod) — в gamma_fw.ld.
    - build.sh: сверяет, что резервы попали в о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
2026-11-05 fw: Task 10 — правки по ревью
    - adc_sig: adc_sig_done() после обработки порции — проверка по seq и CNDTR, не затёр ли DMA
    порцию во время обработки; затёртое — в мёртвое время, счётчик overrun в -gst.
    Свежая половина в прерывании — по CNDTR, а не по порядку флагов HT/TC. Комментарий о сроке
    обработки исправлен (срок от HT/TC, не от take).
    - -noise: mean и σ по «тихим» отсчётам (без выбросов выше mean + 5σ и окрестности −8…+48,
    поро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
2026-11-05 fw: детектор — исправления ревью slowpath: imax = 0, смена порога и ширины посреди импульса
    - fit(): при imax < DET_IPK (максимум на до-триггерном buf[0] после снижения порога или
    падения базы между порциями) окно уходило за начало буфера — теперь отбраковка по форме.
    Ошибка из main (c247193), исправлена и в эталоне tests/detector_ref.c.
    - Вход в импульс между порциями: общий режим, если порог вырос при falling (lpeak < 2·thr)
    и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
2026-11-06 Revert "spec: разбор FWHM 8 % (ФЭУ/оптика ≈7.2 %, обработка ≈1 п.п.), предложение по шейперу; план на завтра"
    This reverts commit 769c9aac0d2dfb8968a9ed8d07d3802b14d7e7c1.
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2026-11-14 docs: SPEC — rec= в -gst с пуска прибора, -tlok требует эталон, журнал
    rec= считается с пуска прибора, как rej_swpb (счётчик детектора, -sta/-rst
    не обнуляют), а не с -sta. -tlok без записанного эталона — -err tl.
    Запись в журнал §10 об исправлениях по итоговому ревью.
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2026-11-14 fw: тесты без ложных «failed», run_tests ловит любые отказы; TAIL без разбора → GUARD; проверки раскладки settings v2/v3
    test_guard_after_tail: брак по форме — приращением, без прогрева. Без разбора детектор бит в бит прежний (cyc --equiv), ОЗУ +0.
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

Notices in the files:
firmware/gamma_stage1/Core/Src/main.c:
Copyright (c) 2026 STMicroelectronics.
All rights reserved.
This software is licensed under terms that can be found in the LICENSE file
